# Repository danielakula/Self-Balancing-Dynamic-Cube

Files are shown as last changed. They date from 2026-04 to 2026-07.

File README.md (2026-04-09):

# Self-Balancing-Dynamic-Cube
Cubli inspired project for 3rd year undergraduate dissertation. Objective is to achieve balance on three edges, corner, and jump from face to edge.

# Contents
ESP32_Tests is written code for each tests done on the firmware.

Edge Balance is the code that implements an inner LQR control loop and a PI outer loop to achieve edge balance on Motor1.

UI Balance is a test which adds wireless UI onto Edge Balance.

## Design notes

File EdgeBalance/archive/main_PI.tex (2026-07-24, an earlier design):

#include <Arduino.h>
#include <Config.h>
#include "Driver.h"
#include "VoltageMonitor.h"
#include "IMU.h"
#include "LQR.h"
#include <atomic>

// Thread-safe mailboxes between Core 0 and Core 1
std::atomic<float> shared_target_torque(0.0f);
std::atomic<float> shared_motor_velocity(0.0f);
std::atomic<float> shared_motor_iq(0.0f);

// Make sure your spinlock flags are volatile so the compiler doesn't optimize them away!
volatile std::atomic<bool> spiRequested(false);
volatile std::atomic<bool> spiSafeToUse(false);

SPIClass hwSpi(1); 
Driver motor1(Motor1Pins, MotorTuning); 
VoltageMonitor battery(VSENSE_PIN, VSENSE_DIVIDER_RATIO, VSENSE_TRIM);

float target = 0.0f;

float target_angle = 0.0f;
float wheel_velocity_integral = 0.0f;

// Outer Loop PI Gains (Start very small!)
float Kp_outer = 0.003f; 
float Ki_outer = 0.0005f;

// Instantiate globally with your specific SPI pins
IMU_Sensor imu(ISM_CS, &hwSpi);

LQR lqr;

Commander command = Commander(Serial);

void taskFOC(void * pvParameters) {
    vTaskDelay(pdMS_TO_TICKS(500));
    // 1. Assassinate the Watchdog on Core 1 so we never have to yield!
    disableCore1WDT(); 

    // 2. Set this specific task to the highest possible FreeRTOS priority
    vTaskPrioritySet(NULL, configMAX_PRIORITIES - 1);

    for(;;) {
        // 1. The Spinlock Handshake
        if (spiRequested.load()) {
            // Core 0 needs the bus. Grant access.
            spiSafeToUse.store(true); 
            
            // Spin in place and wait for Core 0 to finish reading SPI sensors
            while (spiRequested.load()) { 
                // Do nothing. Just wait.
            }
            
            // Core 0 is done. Revoke access and resume math.
            spiSafeToUse.store(false); 
        } else {
            //motor1.setTarget(0.0f);
            motor1.setTarget(shared_target_torque.load());
            motor1.runFOC(); 
            shared_motor_velocity.store(motor1.getVelocity());
            shared_motor_iq.store(motor1.getCurrentQ());
        }
    }
}

void onKpOuter(char* cmd) { 
    command.scalar(&Kp_outer, cmd); 
    Serial.printf("Kp_outer set to: %.6f\n", Kp_outer);
}

void onKiOuter(char* cmd) { 
    command.scalar(&Ki_outer, cmd); 
    Serial.printf("Ki_outer set to: %.6f\n", Ki_outer);
}

void taskLQR(void *pvParameters) {
    uint32_t currentFaults = FAULT_NONE;
    static uint32_t lastFaults = 0xFFFFFFFF; 
    static uint32_t lastPrintTime = 0;
    const uint32_t PRINT_INTERVAL_MS = 200; 

    TickType_t xLastWakeTime = xTaskGetTickCount();
    const TickType_t xFrequency = pdMS_TO_TICKS(5); // 200 Hz LQR loop

    for(;;) {
        currentFaults = FAULT_NONE; 

        if (battery.isUnderVoltage(BATTERY_SAFE_MIN)) currentFaults |= FAULT_UNDER_VOLTAGE;
        if (battery.isOverVoltage(BATTERY_SAFE_MAX))  currentFaults |= FAULT_OVER_VOLTAGE;

        command.run();

        // =======================================================
        // BULLETPROOF SPI BUS ACCESS
        // =======================================================
        spiRequested.store(true); // 1. Ask Core 1 for the bus
        
        while (!spiSafeToUse.load()) { 
            // 2. Wait right here until Core 1 finishes its math and grants access
            delayMicroseconds(1); 
        }

        // 3. We now have 100% exclusive, safe access to the SPI hardware!
        if (motor1.hasHardwareFault()) currentFaults |= FAULT_DRV1;

        // State Machine (emergencyStop/enable might send SPI commands to the DRV chip)
        if (currentFaults != lastFaults) {
            if (currentFaults != FAULT_NONE) {
                motor1.emergencyStop();
                Serial.printf("\n[SYSTEM HALTED] Mask: 0x%08X\n", currentFaults);
            } else {
                motor1.enable();
            }
            lastFaults = currentFaults;
        }

        imu.update(); // Automatically calculates dt and updates state!

        spiRequested.store(false);
        
        float current_wheel_vel = shared_motor_velocity.load();
        
        // ==========================================
        // OUTER LOOP: Shift target angle based on wheel speed
        // ==========================================
        if (currentFaults == FAULT_NONE && abs(imu.getPitch()) < 0.35f) {
            
            // 1. Integrate the wheel velocity
            wheel_velocity_integral += current_wheel_vel * 0.005f; // dt = 5ms
            
            // Optional: Anti-windup for the integral so it doesn't lean too far
            if(wheel_velocity_integral > 500.0f) wheel_velocity_integral = 500.0f;
            if(wheel_velocity_integral < -500.0f) wheel_velocity_integral = -500.0f;

            // 2. Calculate the new target angle
            // If wheel spins positive, tilt positive to catch it.
            target_angle = (Kp_outer * current_wheel_vel) + (Ki_outer * wheel_velocity_integral);
            
            // Clamp target angle to a safe mechanical limit (e.g., +/- 3 degrees)
            const float MAX_TILT = 0.052f; // ~3 degrees in radians
            if (target_angle > MAX_TILT) target_angle = MAX_TILT;
            if (target_angle < -MAX_TILT) target_angle = -MAX_TILT;

        } else {
            // Robot fell over. Reset integrals.
            target_angle = 0.0f;
            wheel_velocity_integral = 0.0f;
        }

        // ==========================================
        // INNER LOOP: Standard LQR
        // ==========================================
        if (currentFaults == FAULT_NONE) {
            if (abs(imu.getPitch()) > 0.35f) {
                target = 0.0f; 
            } else {
                // Compute LQR, but calculate Theta ERROR relative to our new target!
                float theta_error = imu.getPitch() - target_angle;
                
                    target = -lqr.compute(
                    theta_error,            // x1: Angle ERROR
                    imu.getPitchRate(),     // x2: Cube Velocity
                    current_wheel_vel,      // x3: Wheel Velocity
                    0.005f                  // dt: 5ms
                );
            }
        }
        // if (currentFaults == FAULT_NONE) {
        //     if (std::abs(imu.getPitch()) > 0.35f) {
        //         target = 0.0f; 
        //         lqr.resetIntegral(); // Add a quick function to zero wheel_integral in LQR.cpp!
        //     } else {
        //             target = -lqr.compute(
        //             imu.getPitch(),         // x1: Raw Angle
        //             imu.getPitchRate(),     // x2: Cube Velocity
        //             current_wheel_vel,      // x3: Wheel Velocity
        //             0.005f                  // dt: 5ms
        //         );
        //     }
        // }

        // 5. Safely send the torque command to Core 0
        shared_target_torque.store(target);

        // 3. Telemetry Monitor
        if (millis() - lastPrintTime >= PRINT_INTERVAL_MS) {
            lastPrintTime = millis();
            
            // Plotter format: "Label1:Value1,Label2:Value2"
            Serial.printf("Angle:%.2f, PitchRate:%.2f, Target:%.2f, WheelVel:%.2f, Iq:%.2f, Battery:%.2fV\n", 
                          imu.getPitch()*RAD_TO_DEG, 
                          imu.getPitchRate(), target, current_wheel_vel, shared_motor_iq.load(), battery.readVoltage());
        }
        // if (millis() - lastPrintTime >= PRINT_INTERVAL_MS) {
        //     lastPrintTime = millis();
        //     float safe_iq = shared_motor_iq.load();
        //     Serial.printf("Batt: %05.2fV | Angle: %05.2f deg | Cube Velocity: %05.2f | Wheel Velocity:%05.1f Iq:%05.2f Target:%05.2f\n",
        //                   battery.readVoltage(), imu.getPitch(), imu.getPitchRate(), motor1.getVelocity(), motor1.getCurrentQ(), target);
        // }
        
        // Sleep until exactly 5ms have passed
        vTaskDelayUntil(&xLastWakeTime, xFrequency);
    }
}

void setup() {
    Serial.begin(115200);
    delay(2000); // Wait for Serial to initialize
    Serial.println("\n\n=======================================");
    Serial.println("       BALANCE BOT BOOTING...          ");  
    Serial.println("=======================================\n");

    SimpleFOCDebug::enable(&Serial);

    hwSpi.begin(MASTER_SCK, MASTER_MISO, MASTER_MOSI, -1);
    
    motor1.begin(&hwSpi);
    battery.begin();

    lqr.setCurrentLimit(MotorTuning.current_limit);
    
    if (!imu.init()) {
        Serial.println("IMU init failed!");
        while (1);
    }
    
    imu.calibrate();

    command.add('P', onKpOuter, "Outer Loop Kp");
    command.add('I', onKiOuter, "Outer Loop Ki");

    disableCore0WDT();

    // Pin FOC to Core 0 (Priority 5 - Highest)
    xTaskCreatePinnedToCore(taskFOC, "MotorTask", 8192, NULL, 5, NULL, 1);
    
    // Pin LQR to Core 1 (Priority 4 - High)
    xTaskCreatePinnedToCore(taskLQR, "LQR_Task", 8192, NULL, 4, NULL, 0);
}

void loop() {
    vTaskDelete(NULL); 
}

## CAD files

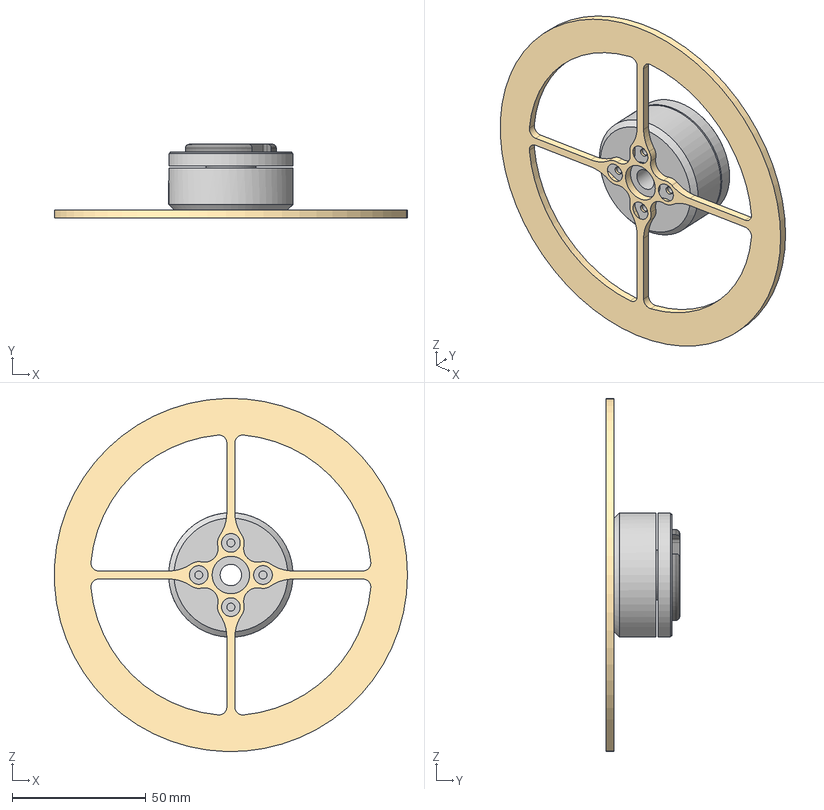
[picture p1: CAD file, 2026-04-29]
SIMULATIONS/Edge Balance/Discretised/Motor and Wheel (Assembly).step
131.9 x 27.5 x 132.0 mm
Motor and Wheel
15RW4S
GL40

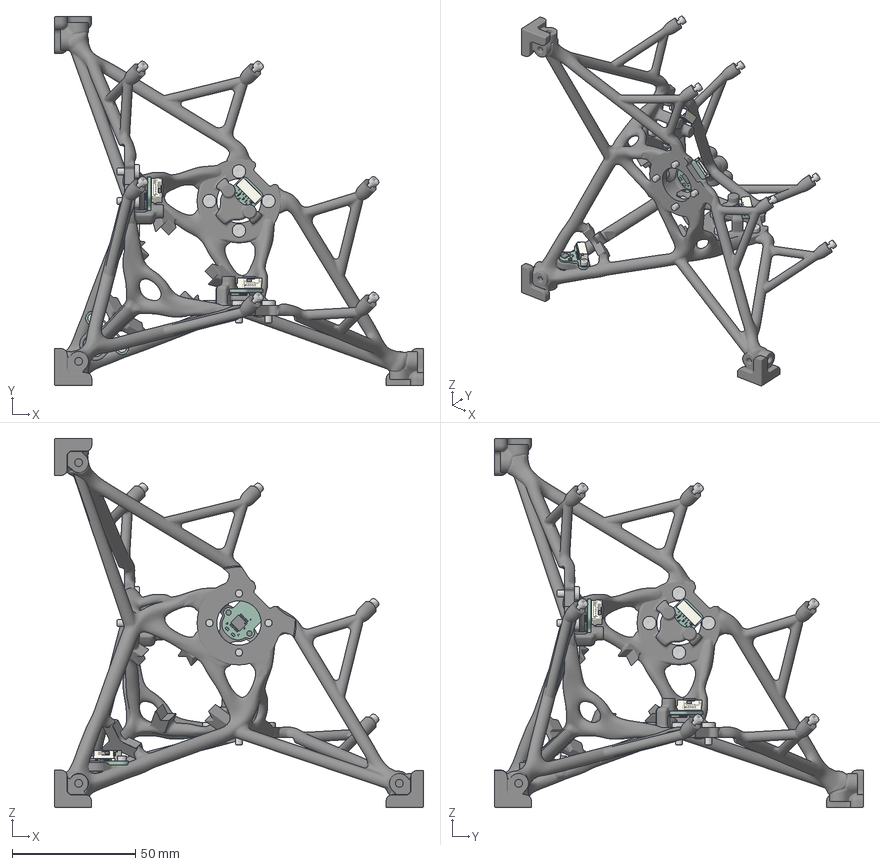
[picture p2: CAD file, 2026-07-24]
SIMULATIONS/Edge Balance/Discretised/coreModel.3mf
150.0 x 150.0 x 150.0 mm

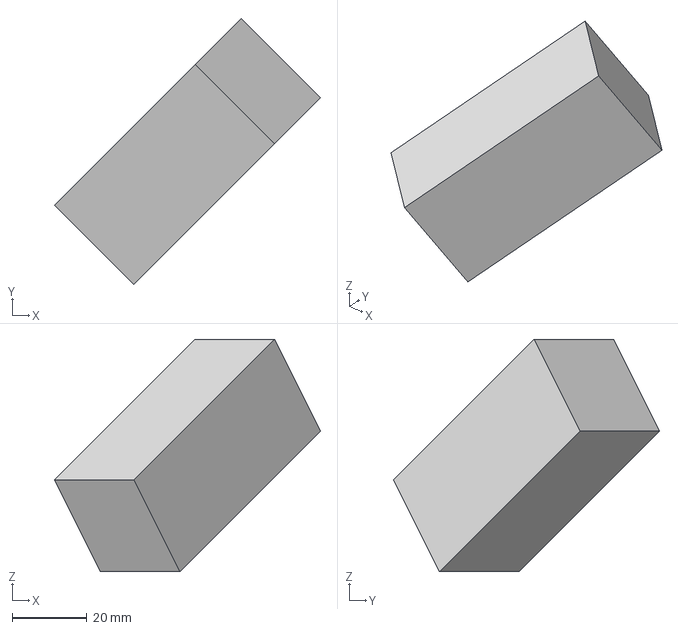
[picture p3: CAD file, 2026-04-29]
SIMULATIONS/Edge Balance/Discretised/BatteryModel.step
71.0 x 71.0 x 62.0 mm

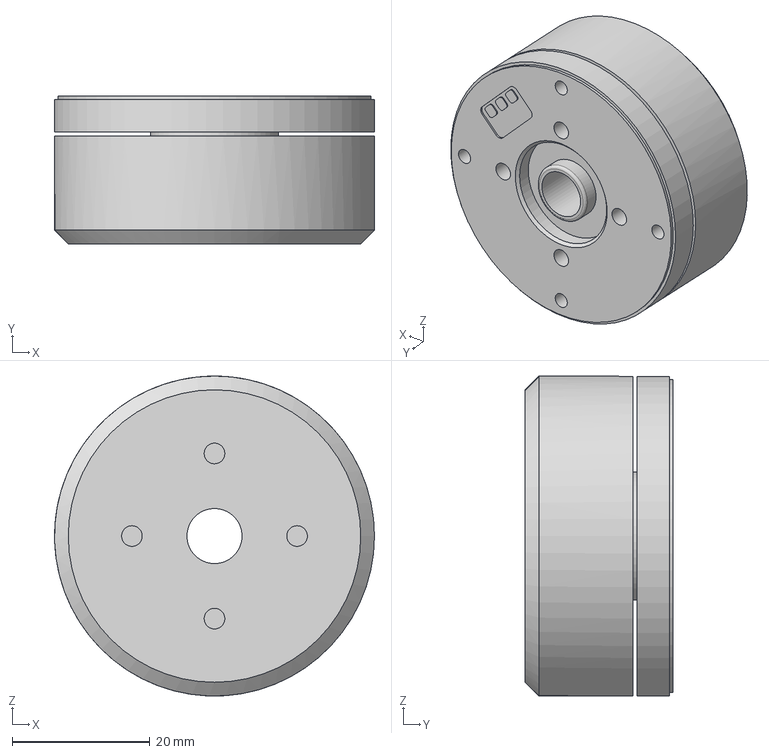
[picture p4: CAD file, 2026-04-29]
SIMULATIONS/Edge Balance/Discretised/Motor.step
46.5 x 21.5 x 46.5 mm

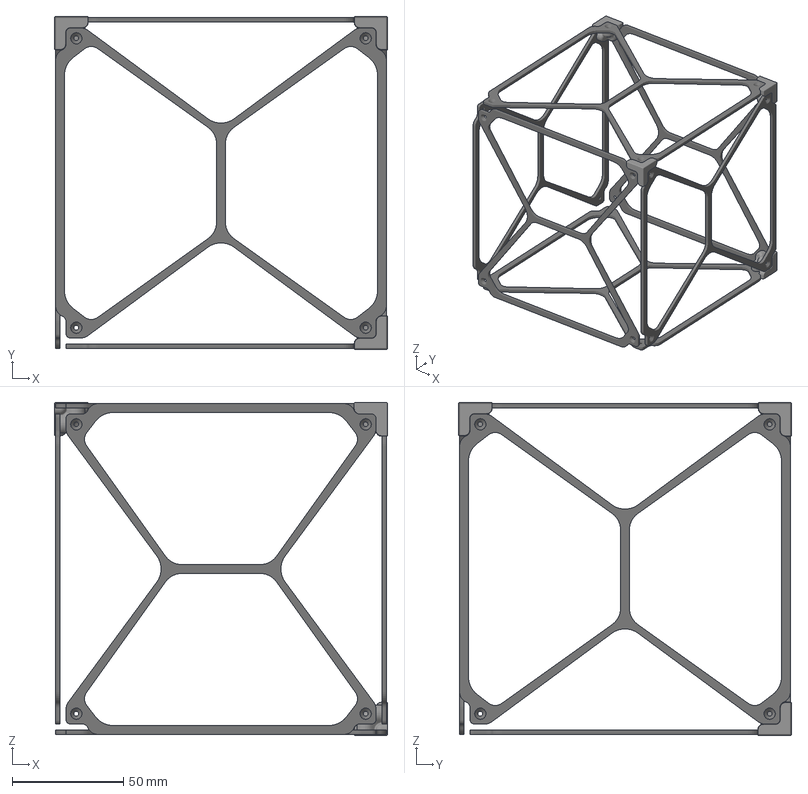
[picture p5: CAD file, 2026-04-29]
SIMULATIONS/Edge Balance/Discretised/FrameModel.3mf
150.0 x 150.0 x 150.0 mm

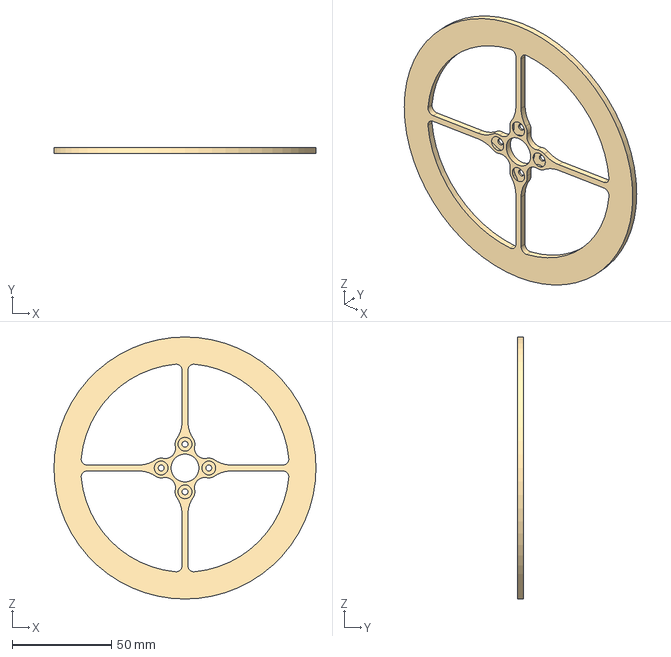
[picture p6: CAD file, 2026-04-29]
SIMULATIONS/Edge Balance/Discretised/RW.step
132.0 x 3.00 x 132.0 mm

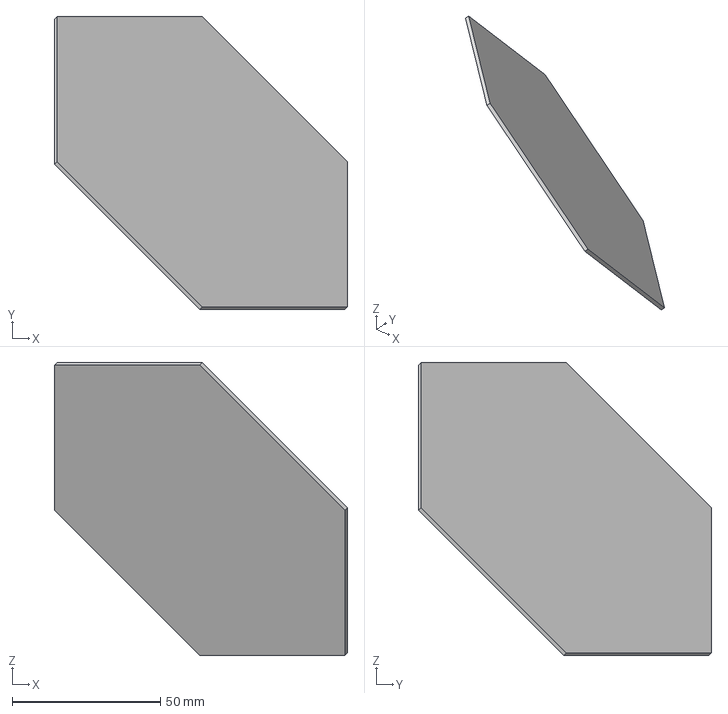
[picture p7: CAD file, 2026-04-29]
SIMULATIONS/Edge Balance/Discretised/PCBModel.step
98.9 x 98.9 x 98.9 mm

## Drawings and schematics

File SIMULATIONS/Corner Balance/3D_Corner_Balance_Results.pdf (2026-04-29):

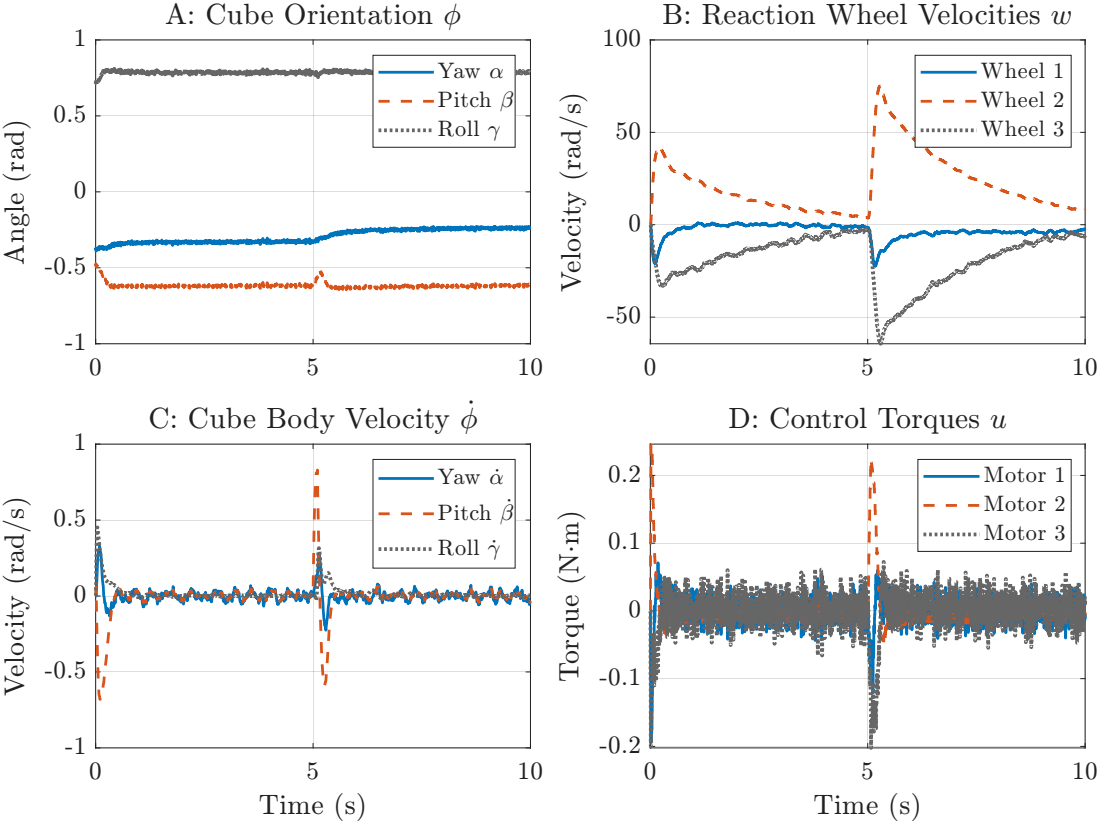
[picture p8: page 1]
gle (r; A: Cube Orientation ?; Yaw , Pitch - Roll .; Velo; cit; Wheel 1 Wheel 2 Wheel 3; Time (s); Yaw ,_ Pitch -_; Roll ._; D: Control Torques u; Motor 1 Motor 2 Motor 3

B: Reaction Wheel Velocities w

C: Cube Body Velocity ?_

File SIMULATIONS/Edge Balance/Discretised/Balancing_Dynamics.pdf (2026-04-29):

C
u

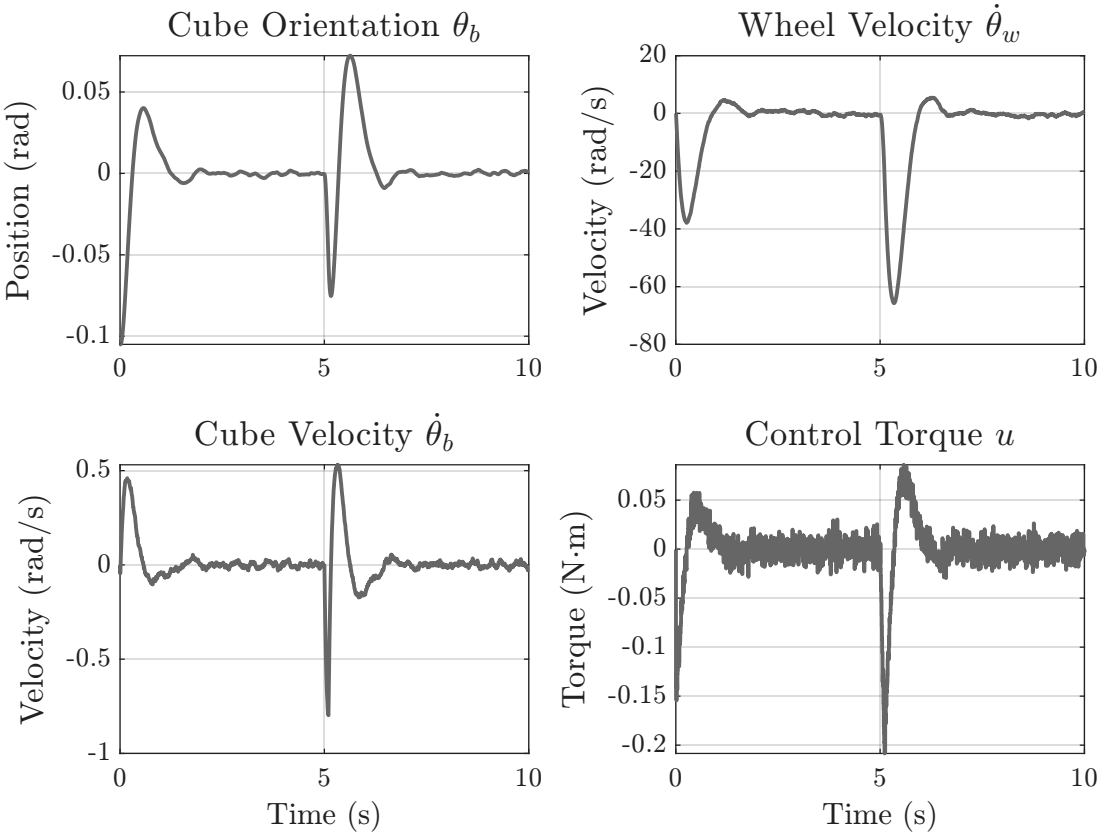
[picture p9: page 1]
Position (rad); Velocity (rad/s); Torque (N"m)

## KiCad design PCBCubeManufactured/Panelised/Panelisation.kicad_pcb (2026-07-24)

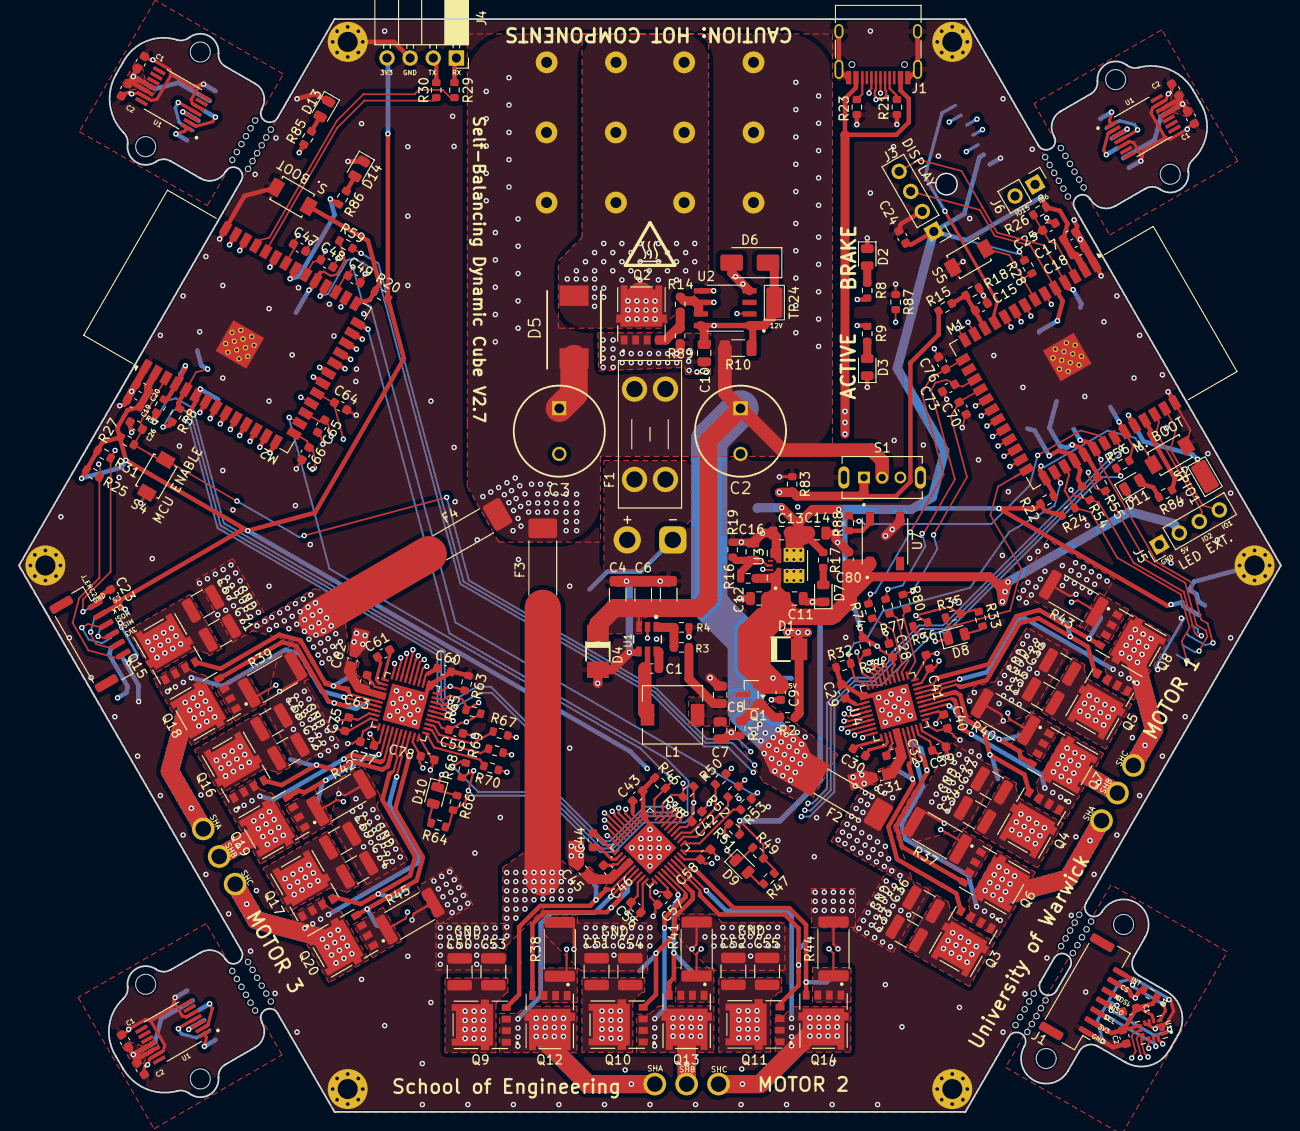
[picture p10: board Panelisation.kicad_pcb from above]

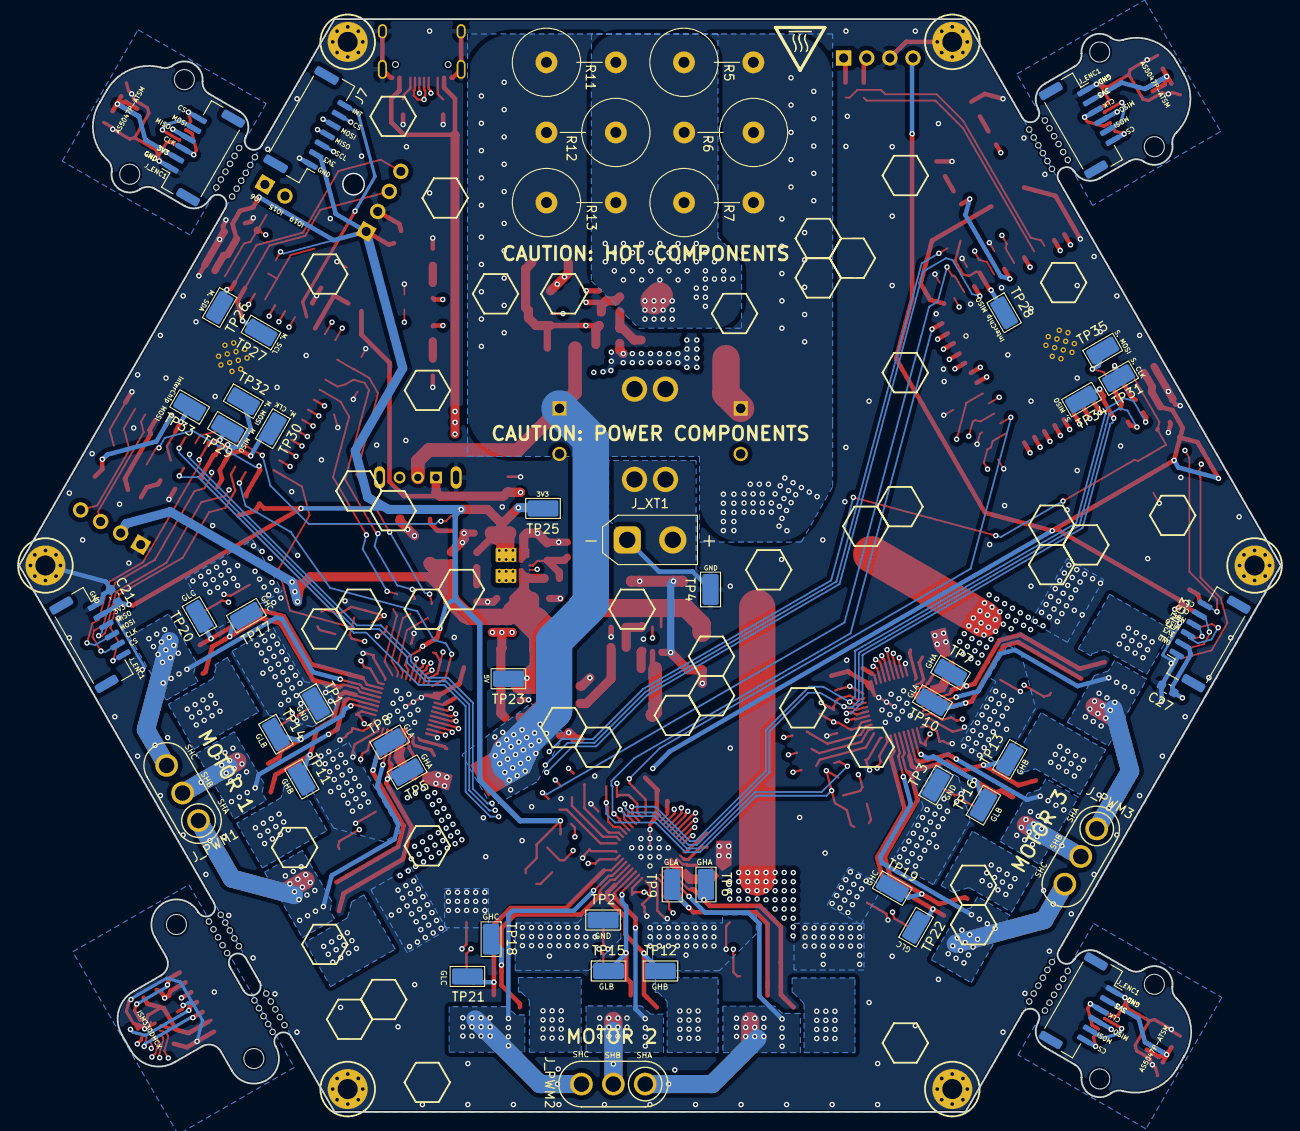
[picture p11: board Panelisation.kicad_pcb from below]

Board: 4 copper layers, 138.6 x 120.0 mm, 291 parts (53 on the bottom side), 181 nets.

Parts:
C1, C1#2, C1#3, C1#4, C1#5, C2#2, C15, C18, C20, C21, C23, C24, C27, C28, C31, C42, C45, C59, C62, C80: 100nF; C_0603_1608Metric
C2, C3: EEU-FC1H471L; CAPPRD500W85D1000H3200
C2#3, C2#4, C2#5, C9, C17, C19: 10uF; C_0603_1608Metric
C4, C5: 4.7uF; C_1206_3216Metric
C6: 100nF; C_1206_3216Metric
C7, C8: 47uF; C_0805_2012Metric
C10, C11, C16: 10uF; C_0805_2012Metric
C12: 100nF; C_0805_2012Metric
C13, C14: 22uF; C_0805_2012Metric
C25, C26, C29, C32, C43, C46, C60, C63: 1uF; C_0603_1608Metric
C30, C44, C61: 47nF; C_0603_1608Metric
C33, C34, C35, C36, C37, C38, C50, C51, C52, C53, C54, C55, C67, C68, C69, C71, C72, C74: 10uF; C_1210_3225Metric
C39, C40, C41, C56, C57, C58, C75, C77, C78: 1000pF; C_0603_1608Metric
C47, C48, C49, C64, C65, C66, C70, C73, C76: 2.2nF; C_0603_1608Metric
D1, D4: D_Schottky SS34; DO-214AC
D2, D8, D9, D10, D11, D14: LED R; LED_0805_2012Metric
D3, D7, D13: LED G; LED_0805_2012Metric
D5: D_Schottky SS1045; DIOM8059X256N
D6: 12V Zener; D_SMA
F1: 3568; Fuseholder_Blade_Mini_Keystone_3568
F2, F3, F4: 0456020.ER; FUSC10030X305N
H1, H2, H3, H4, H5, H6: MountingHole_Pad; MountingHole_2.19mm_M2_Pad_Via
J1, J7: Conn_01x07; JST_GH_BM07B-GHS-TBT_1x07-1MP_P1.25mm_Vertical
J1#2: USB_C_Receptacle_USB2.0_16P; USB_C_Receptacle_HRO_TYPE-C-31-M-12
J3, J5: Conn_01x04; PinHeader_1x04_P2.54mm_Vertical
J4: Conn_01x04; PinSocket_1x04_P2.54mm_Horizontal
J6: Conn_01x02; PinHeader_1x02_P2.54mm_Vertical
J_ENC1, J_ENC1#2, J_ENC1#3, J_ENC1#4, J_ENC2, J_ENC3: Conn_01x06; JST_GH_SM06B-GHS-TB_1x06-1MP_P1.25mm_Horizontal
J_PWM1, J_PWM2, J_PWM3: Conn_01x03; Amass_MR30PB-M
J_XT1: XT30UPB-M; AMASS_XT30UPB-M_1x02_P5.0mm_Vertical
L1: 4.7uH; L_6.3x6.3_H3
LOGO3, LOGO3#2: CAUTION HOT SURFACE; IEC_HotSurface_Small
M1, M2: ESP32-S3-WROOM-1
NT1, NT2, NT3, NT4, NT5, NT6, NT7, NT8, NT9, NT10: NetTie_2; NET-TIE-0.25mm
Q1: AO3401A; SOT-23
Q2, Q3, Q4, Q5, Q6, Q7, Q8, Q9, Q10, Q11, Q12, Q13, Q14, Q15, Q16, Q17, Q18, Q19, Q20: NTMFS5C612N; NTMFS5C430NT1G
R1, R1#2, R18, R19, R20, R22, R26, R27, R28, R87, R89: 10k; R_0603_1608Metric
R2: 1k; R_0603_1608Metric
R3, R15, R83: 100k; R_0603_1608Metric
R4: 19.1k; R_0603_1608Metric
R5, R6, R7, R11, R12, R13: AC07000003308JAC00; AC05
R8, R9: 2.2k; R_0603_1608Metric
R10: 330; R_1206_3216Metric
R14: 10; R_0603_1608Metric
R16: 15.8k; R_0603_1608Metric
R17: 470; R_0603_1608Metric
R21, R23: 5.1k; R_0603_1608Metric
R24, R25, R31, R32, R34, R35, R36, R46, R48, R49, R51, R63, R65, R66, R68: 10K; R_0603_1608Metric
R29, R30, R84, R85, R86, R88: 330; R_0603_1608Metric
R33, R47, R64: 1.5k; R_0603_1608Metric
R37, R38, R39, R40, R41, R42, R43, R44, R45: Shunt; R_2512_6332Metric
R50, R52, R53, R67, R69, R70, R74, R77, R80: 56; R_0603_1608Metric
R54, R55, R56, R57, R58, R59: 33; R_0603_1608Metric
S1: SS12D07VG4; SW_SS12D07VG4
S2, S3, S4, S5: TS-1088-AR02016; SW_TS-1088-AR02016
TP1, TP2, TP3, TP4, TP5, TP6, TP7, TP8, TP9, TP10, TP11, TP12, TP13, TP14, TP15, TP16, TP17, TP18, TP19, TP20, TP21, TP22, TP23, TP24, TP25, TP26, TP27, TP28, TP29, TP30, TP31, TP32, TP33, TP34, TP35: TestPoint; TestPoint_Keystone_5015_Micro_Mini
TPIO1: TestPoint; TestPoint_Keystone_5015_Micro_Mini
U1, U1#3, U1#5: AS5047P-ATSM; SOP65P640X120-14N
U1#2: LMR51625YFDDCR; DDC0006A-MFG
U1#4: ISM330DHCX; PQFN50P250X300X86-14N
U2: MCP1407-E_SN
U3: TPSM863253RDXR; VREG_TPSM863253RDXR
U4, U5, U6: DRV8323SRTAT; DRV8323SRTAT_update_solder
U7: WS2812B-B; LED_WS2812B-B

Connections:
+3V3: C1.1, C1#2.1, C1#4.1, C1#5.1, C2#2.1, C2#3.1, C2#4.1, C2#5.1, C13.2, C14.2, C17.2, C18.2, C19.2, C20.2, C21.2, C23.2, C24.2, C27.2, C28.2, C42.2, C59.2, J1.2, J3.1, J4.4, J7.2, J_ENC1.2, J_ENC1#2.2, J_ENC1#3.2, J_ENC1#4.2, J_ENC2.2, J_ENC3.2, M1.2 (3V3), M2.2 (3V3), R1#2.2, R17.2, R20.1, R22.1, R24.2, R25.2, R26.1, R27.1, R28.1, R31.2, R33.1, R34.2, R35.2, R36.2, R47.1, R48.2, R49.2, R51.2, R64.1, R65.2, R66.2, R68.2, TP25.1, U1.11 (VDD), U1.12 (VDD3V3), U1#3.11 (VDD), U1#3.12 (VDD3V3), U1#4.5 (VDD_IO), U1#4.8 (VDD), U1#5.11 (VDD), U1#5.12 (VDD3V3), U3.3 (VOUT), U3.7 (FB), U4.24 (VREF), U5.24 (VREF), U6.24 (VREF)
+5V: C9.2, C11.2, C12.2, C80.2, D1.1 (K), J5.2, Q1.2 (S), R16.1, TP23.1, U3.1 (VIN), U7.1 (VDD)
+5V Buck: C7.2, C8.2, L1.2, Q1.3 (D), R3.1
+5V USB: D1.2 (A), J1#2.A4 (VBUS), J1#2.A9 (VBUS), J1#2.B4 (VBUS), J1#2.B9 (VBUS), R2.1
/AO3401A Gate: Q1.1 (G), R1.1, R2.2
/BR3_EN: C16.2, R16.2, R19.2, U3.6 (EN)
/BR5_CB: C1#3.2, U1#2.6 (CB)
/BR5_FB: R3.2, R4.2, U1#2.1 (FB)
/BR5_SW: C1#3.1, L1.1, U1#2.5 (SW)
/BR_LEDG: D3.2 (A), R9.1
/BR_LEDR: D2.2 (A), R8.1
/CC1: J1#2.A5 (CC1), R21.2
/CC2: J1#2.B5 (CC2), R23.1
/CLK: J_ENC1.3, J_ENC1#3.3, J_ENC1#4.3, U1.2 (CLK), U1#3.2 (CLK), U1#5.2 (CLK)
/CS: J_ENC1.6, J_ENC1#3.6, J_ENC1#4.6, U1.1 (CSN), U1#3.1 (CSN), U1#5.1 (CSN)
/DIN: R88.2, U7.4 (DIN)
/Drain_Brake: D5.2 (A), Q2.5 (D), R5.1, R6.2, R7.1, R11.2, R12.1, R13.2
/Driver1/CPH1: C30.1, U4.2 (CPH)
/Driver1/CPL1: C30.2, U4.1 (CPL)
/Driver1/DVDD: C29.2, U4.33 (DVDD)
/Driver1/GHA: Q3.4 (G), TP5.1, U4.6 (GHA)
/Driver1/GHB: Q4.4 (G), TP11.1, U4.15 (GHB)
/Driver1/GHC: Q5.4 (G), TP17.1, U4.16 (GHC)
/Driver1/GLA: Q6.4 (G), TP8.1, U4.8 (GLA)
/Driver1/GLB: Q7.4 (G), TP14.1, U4.13 (GLB)
/Driver1/GLC: Q8.4 (G), TP20.1, U4.18 (GLC)
/Driver1/LED R1: D8.2 (A), R33.2
/Driver1/PhaseA: J_PWM1.1, Q3.1 (S), Q6.5 (D), U4.7 (SHA)
/Driver1/PhaseB: J_PWM1.2, Q4.1 (S), Q7.5 (D), U4.14 (SHB)
/Driver1/PhaseC: J_PWM1.3, Q5.1 (S), Q8.5 (D), U4.17 (SHC)
/Driver1/SNA: C39.1, NT4.2, U4.10 (SNA)
/Driver1/SNB: C40.1, NT2.2, U4.11 (SNB)
/Driver1/SNC: C41.1, NT3.2, U4.20 (SNC)
/Driver1/SPA: C39.2, Q6.1 (S), R37.1, U4.9 (SPA)
/Driver1/SPB: C40.2, Q7.1 (S), R40.1, U4.12 (SPB)
/Driver1/SPC: C41.2, Q8.1 (S), R43.1, U4.19 (SPC)
/Driver1/VCP1: C32.2, U4.3 (VCP)
/Driver1/VFuse: C31.2, C32.1, C33.2, C34.2, C35.2, C36.2, C37.2, C38.2, F2.1, Q3.5 (D), Q4.5 (D), Q5.5 (D), U4.4 (VM), U4.5 (VDRAIN)
/Driver2/CPH1: C44.1, U5.2 (CPH)
/Driver2/CPL1: C44.2, U5.1 (CPL)
/Driver2/DVDD: C43.2, U5.33 (DVDD)
/Driver2/GHA: Q9.4 (G), TP6.1, U5.6 (GHA)
/Driver2/GHB: Q10.4 (G), TP12.1, U5.15 (GHB)
/Driver2/GHC: Q11.4 (G), TP18.1, U5.16 (GHC)
/Driver2/GLA: Q12.4 (G), TP9.1, U5.8 (GLA)
/Driver2/GLB: Q13.4 (G), TP15.1, U5.13 (GLB)
/Driver2/GLC: Q14.4 (G), TP21.1, U5.18 (GLC)
/Driver2/LED R1: D9.2 (A), R47.2
/Driver2/PhaseA: J_PWM2.1, Q9.1 (S), Q12.5 (D), U5.7 (SHA)
/Driver2/PhaseB: J_PWM2.2, Q10.1 (S), Q13.5 (D), U5.14 (SHB)
/Driver2/PhaseC: J_PWM2.3, Q11.1 (S), Q14.5 (D), U5.17 (SHC)
/Driver2/SNA: C56.1, NT7.2, U5.10 (SNA)
/Driver2/SNB: C57.1, NT5.2, U5.11 (SNB)
/Driver2/SNC: C58.1, NT6.2, U5.20 (SNC)
/Driver2/SPA: C56.2, Q12.1 (S), R38.1, U5.9 (SPA)
/Driver2/SPB: C57.2, Q13.1 (S), R41.1, U5.12 (SPB)
/Driver2/SPC: C58.2, Q14.1 (S), R44.1, U5.19 (SPC)
/Driver2/VCP1: C46.2, U5.3 (VCP)
/Driver2/VFuse: C45.2, C46.1, C50.2, C51.2, C52.2, C53.2, C54.2, C55.2, F3.1, Q9.5 (D), Q10.5 (D), Q11.5 (D), U5.4 (VM), U5.5 (VDRAIN)
/Driver3/CPH1: C61.1, U6.2 (CPH)
/Driver3/CPL1: C61.2, U6.1 (CPL)
/Driver3/DVDD: C60.2, U6.33 (DVDD)
/Driver3/GHA: Q15.4 (G), TP7.1, U6.6 (GHA)
/Driver3/GHB: Q16.4 (G), TP13.1, U6.15 (GHB)
/Driver3/GHC: Q17.4 (G), TP19.1, U6.16 (GHC)
/Driver3/GLA: Q18.4 (G), TP10.1, U6.8 (GLA)
/Driver3/GLB: Q19.4 (G), TP16.1, U6.13 (GLB)
/Driver3/GLC: Q20.4 (G), TP22.1, U6.18 (GLC)
/Driver3/LED R1: D10.2 (A), R64.2
/Driver3/PhaseA: J_PWM3.1, Q15.1 (S), Q18.5 (D), U6.7 (SHA)
/Driver3/PhaseB: J_PWM3.2, Q16.1 (S), Q19.5 (D), U6.14 (SHB)
/Driver3/PhaseC: J_PWM3.3, Q17.1 (S), Q20.5 (D), U6.17 (SHC)
/Driver3/SNA: C75.1, NT10.2, U6.10 (SNA)
/Driver3/SNB: C77.1, NT8.2, U6.11 (SNB)
/Driver3/SNC: C78.1, NT9.2, U6.20 (SNC)
/Driver3/SPA: C75.2, Q18.1 (S), R39.1, U6.9 (SPA)
/Driver3/SPB: C77.2, Q19.1 (S), R42.1, U6.12 (SPB)
/Driver3/SPC: C78.2, Q20.1 (S), R45.1, U6.19 (SPC)
/Driver3/VCP1: C63.2, U6.3 (VCP)
/Driver3/VFuse: C62.2, C63.1, C67.2, C68.2, C69.2, C71.2, C72.2, C74.2, F4.1, Q15.5 (D), Q16.5 (D), Q17.5 (D), U6.4 (VM), U6.5 (VDRAIN)
/Gate_Brake: Q2.4 (G), R14.1, R89.1
/I.C. MISO: M2.31 (IO38), R59.1, TP28.1
/I.C. MOSI: M1.35 (IO42), R56.1, TP33.1
/LEDG: D7.2 (A), R17.1
/M. CLK: M1.30 (IO37), R54.1, TP30.1
/M. LEDR: D11.2 (A), R84.2
/M. MOSI: M1.31 (IO38), R55.1, TP32.1
/MISO: J_ENC1.4, J_ENC1#3.4, J_ENC1#4.4, U1.3 (MISO), U1#3.3 (MISO), U1#5.3 (MISO)
/MOSI: J_ENC1.5, J_ENC1#3.5, J_ENC1#4.5, U1.4 (MOSI), U1#3.4 (MOSI), U1#5.4 (MOSI)
/Out: R8.2, R14.2, U2.6 (OUT), U2.7 (OUT)
/S. CLK: M2.4 (IO4), R57.2, TP31.1
/S. LEDG: D13.2 (A), R85.2
/S. LEDR: D14.2 (A), R86.2
/S. MOSI: M2.5 (IO5), R58.2, TP35.1
/SRX: J4.1, R30.1
/STX: J4.2, R29.1
/V_XT30: F1.1, J_XT1.2 (+)
Debug1: J6.1, M1.6 (IO6)
Debug2: J6.2, M1.8 (IO15)
Display Button: M1.7 (IO7), R28.2, S5.2
Enable1: M1.28 (IO35), R32.2, U4.30 (ENABLE)
Enable2: M2.16 (IO46), R46.2, U5.30 (ENABLE)
Enable3: M2.14 (USB_D+), R63.2, U6.30 (ENABLE)
Fault1: D8.1 (K), M1.26 (IO45), R35.1, U4.25 (NFAULT)
Fault2: D9.1 (K), M2.26 (IO45), R49.1, U5.25 (NFAULT)
Fault3: D10.1 (K), M2.13 (USB_D-), R66.1, U6.25 (NFAULT)
GND: C1.2, C1#2.2, C1#4.2, C1#5.2, C2.2 (-), C2#2.2, C2#3.2, C2#4.2, C2#5.2, C3.2 (-), C4.1, C5.1, C6.1, C7.1, C8.1, C9.1, C10.2, C11.1, C12.1, C13.1, C14.1, C15.1, C16.1, C17.1, C18.1, C19.1, C20.1, C21.1, C23.1, C24.1, C25.2, C26.2, C27.1, C28.1, C29.1, C31.1, C33.1, C34.1, C35.1, C36.1, C37.1, C38.1, C42.1, C43.1, C45.1, C47.1, C48.1, C49.1, C50.1, C51.1, C52.1, C53.1, C54.1, C55.1, C59.1, C60.1, C62.1, C64.1, C65.1, C66.1, C67.1, C68.1, C69.1, C70.1, C71.1, C72.1, C73.1, C74.1, C76.1, C80.1, D2.1 (K), D3.1 (K), D4.2 (A), D6.2 (A), D7.1 (K), D11.1 (K), D13.1 (K), D14.1 (K), H1.1, H2.1, H3.1, H4.1, H5.1, H6.1, J1.1, J1#2.A1 (GND), J1#2.A12 (GND), J1#2.B1 (GND), J1#2.B12 (GND), J1#2.S1 (SHIELD), J3.2, J4.3, J5.1, J7.1, J_ENC1.1, J_ENC1#2.1, J_ENC1#3.1, J_ENC1#4.1, J_ENC2.1, J_ENC3.1, J_XT1.1 (-), M1.1 (GND), M1.40 (GND), M1.41 (GND), M2.1 (GND), M2.40 (GND), M2.41 (GND), NT2.1, NT3.1, NT4.1, NT5.1, NT6.1, NT7.1, NT8.1, NT9.1, NT10.1, Q2.1 (S), R1.2, R4.1, R18.1, R19.1, R21.1, R23.2, R32.1, R37.2, R38.2, R39.2, R40.2, R41.2, R42.2, R43.2, R44.2, R45.2, R46.1, R63.1, R83.1, R87.1, R89.2, S1.S1 (SHIELD), S1.S2 (SHIELD), S2.1, S3.1, S4.1, S5.1, TP1.1, TP2.1, TP3.1, TP4.1, U1.5 (TEST), U1.13 (GND), U1#2.4 (GND), U1#3.5 (TEST), U1#3.13 (GND), U1#4.2 (SDX), U1#4.3 (SCX), U1#4.6 (GND), U1#4.7 (GND), U1#5.5 (TEST), U1#5.13 (GND), U2.4 (GND), U2.5 (GND), U3.4 (PGND), U4.31 (CAL), U4.32 (AGND), U4.40 (PGND), U4.41 (EXP), U5.31 (CAL), U5.32 (AGND), U5.40 (PGND), U5.41 (EXP), U6.31 (CAL), U6.32 (AGND), U6.40 (PGND), U6.41 (EXP), U7.3 (VSS)
IMU_CS: J1.6, J7.6, M1.9 (IO16), R1#2.1, U1#4.12 (CS)
IMU_INT: J1.7, J7.7, M1.11 (IO18), U1#4.4 (INT1)
INHA1: M1.24 (IO47), U4.34 (INHA)
INHA2: M2.25 (IO48), U5.34 (INHA)
INHA3: M2.12 (IO8), U6.34 (INHA)
INHB1: M1.22 (IO14), U4.36 (INHB)
INHB2: M2.23 (IO21), U5.36 (INHB)
INHB3: M2.10 (IO17), U6.36 (INHB)
INHC1: M1.20 (IO12), U4.38 (INHC)
INHC2: M2.21 (IO13), U5.38 (INHC)
INHC3: M2.8 (IO15), U6.38 (INHC)
INLA1: M1.23 (IO21), U4.35 (INLA)
INLA2: M2.24 (IO47), U5.35 (INLA)
INLA3: M2.11 (IO18), U6.35 (INLA)
INLB1: M1.21 (IO13), U4.37 (INLB)
INLB2: M2.22 (IO14), U5.37 (INLB)
INLB3: M2.9 (IO16), U6.37 (INLB)
INLC1: M1.19 (IO11), U4.39 (INLC)
INLC2: M2.20 (IO12), U5.39 (INLC)
INLC3: M2.7 (IO7), U6.39 (INLC)
InterChip MISO: M1.34 (IO41), R59.2
InterChip MOSI: M2.30 (IO37), R56.2
LED1: J5.3, M1.38 (IO2)
LED2: J5.4, M1.39 (IO1)
LED3: M1.33 (IO40), R88.1
Master Boot: M1.27 (IO0), R22.2, S2.2
Master CLK: J1.3, J7.3, J_ENC1#2.3, R54.2, U1#4.13 (SCL), U4.28 (SCLK)
Master DRV1 CS: M1.25 (IO48), R34.1, U4.29 (NSCS)
Master EN: C25.1, M1.3 (EN), NT1.1, R26.2, S4.2
Master ENC1 CS: J_ENC1#2.6, M1.29 (IO36), R24.1
Master LEDR: M1.37 (TXD0), R84.1
Master MISO: J1.4, J7.4, J_ENC1#2.4, M1.32 (IO39), R36.1, TP29.1, U1#4.1 (SDO/SA0), U4.26 (SDO)
Master MOSI: J1.5, J7.5, J_ENC1#2.5, R55.2, U1#4.14 (SDA), U4.27 (SDI)
Master SCL: J3.3, M1.5 (IO5), TP27.1
Master SDA: J3.4, M1.4 (IO4), TP26.1
unnamed: R74.2, U4.23 (SOA)
unnamed: R77.2, U4.22 (SOB)
unnamed: R80.2, U4.21 (SOC)
unnamed: R50.2, U5.23 (SOA)
unnamed: R52.2, U5.22 (SOB)
unnamed: R53.2, U5.21 (SOC)
unnamed: R67.2, U6.23 (SOA)
unnamed: R69.2, U6.22 (SOB)
unnamed: R70.2, U6.21 (SOC)
SOA1: C76.2, M1.15 (IO3), R74.1
SOA2: C47.2, M2.34 (IO41), R50.1
SOA3: C64.2, M2.19 (IO11), R67.1
SOB1: C73.2, M1.17 (IO9), R77.1
SOB2: C48.2, M2.32 (IO39), R52.1
SOB3: C65.2, M2.17 (IO9), R69.1
SOC1: C70.2, M1.18 (IO10), R80.1
SOC2: C49.2, M2.29 (IO36), R53.1
SOC3: C66.2, M2.15 (IO3), R70.1
Slave Boot: M2.27 (IO0), R20.2, S3.2
Slave CLK: J_ENC2.3, J_ENC3.3, R57.1, U5.28 (SCLK), U6.28 (SCLK)
Slave DRV2 CS: M2.28 (IO35), R48.1, U5.29 (NSCS)
Slave DRV3 CS: M2.18 (IO10), R65.1, U6.29 (NSCS)
Slave EN: C26.1, M2.3 (EN), NT1.2, R27.2
Slave ENC2 CS: J_ENC2.6, M2.39 (IO1), R25.1
Slave ENC3 CS: J_ENC3.6, M2.38 (IO2), R31.1
Slave LEDG: M2.35 (IO42), R85.1
Slave LEDR: M2.33 (IO40), R86.1
Slave MISO: J_ENC2.4, J_ENC3.4, M2.6 (IO6), R51.1, R68.1, TP34.1, U5.26 (SDO), U6.26 (SDO)
Slave MOSI: J_ENC2.5, J_ENC3.5, R58.1, U5.27 (SDI), U6.27 (SDI)
Slave RX: M2.36 (RXD0), R29.2
Slave TX: M2.37 (TXD0), R30.2
TestPoint M.: M1.36 (RXD0), TPIO1.1
USB_D+: J1#2.A6 (D+), J1#2.B6 (D+), M1.14 (USB_D+)
USB_D-: J1#2.A7 (D-), J1#2.B7 (D-), M1.13 (USB_D-)
VBAT: C2.1 (+), C3.1 (+), C4.2, C5.2, C6.2, D4.1 (K), D5.1 (K), F1.2, F2.2, F3.2, F4.2, R5.2, R6.1, R7.2, R10.2, R11.1, R12.2, R13.1, S1.2, U1#2.3 (VIN)
VBat Sense: C15.2, M1.12 (IO8), R15.1, R18.2
VDD: C10.1, D6.1 (K), R9.2, R10.1, TP24.1, U2.1 (VDD), U2.8 (VDD)
VSwitch: R15.2, R83.2, S1.1, U1#2.2 (EN)
Voltage Protection: M1.10 (IO17), R87.2, U2.2 (INPUT)

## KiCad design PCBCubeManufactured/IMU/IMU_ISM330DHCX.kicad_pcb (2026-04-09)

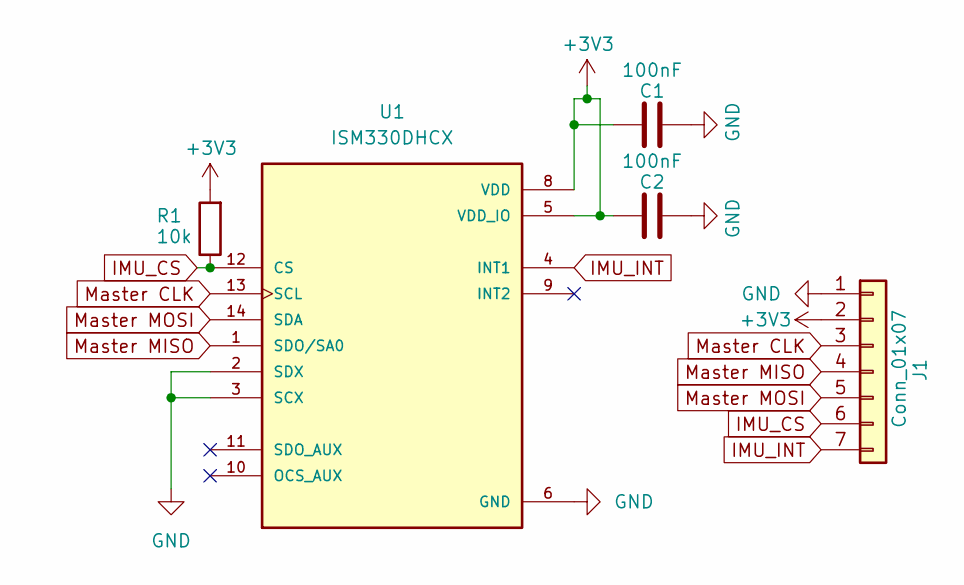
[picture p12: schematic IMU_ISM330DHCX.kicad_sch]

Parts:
C1, C2: 100nF; C_0603_1608Metric; LCSC C14663
J1: Conn_01x07; JST_GH_BM07B-GHS-TBT_1x07-1MP_P1.25mm_Vertical
R1: 10k; R_0603_1608Metric; LCSC C25804
U1: ISM330DHCX; PQFN50P250X300X86-14N; PARTREV 7; LCSC C2655101

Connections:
+3V3: C1.1, C2.1, J1.2, R1.2, U1.5 (VDD_IO), U1.8 (VDD)
GND: C1.2, C2.2, J1.1, U1.2 (SDX), U1.3 (SCX), U1.6 (GND), U1.7 (GND)
IMU_CS: J1.6, R1.1, U1.12 (CS)
IMU_INT: J1.7, U1.4 (INT1)
Master CLK: J1.3, U1.13 (SCL)
Master MISO: J1.4, U1.1 (SDO/SA0)
Master MOSI: J1.5, U1.14 (SDA)

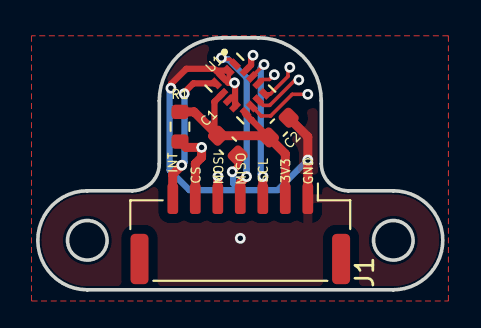
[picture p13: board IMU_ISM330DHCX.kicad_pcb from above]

Board: 4 copper layers, 22.5 x 14.0 mm, 5 parts (0 on the bottom side), 7 nets.

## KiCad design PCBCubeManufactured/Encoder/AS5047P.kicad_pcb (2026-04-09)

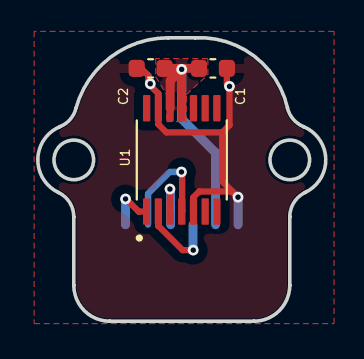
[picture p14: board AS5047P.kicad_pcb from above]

Board: 4 copper layers, 16.0 x 15.7 mm, 4 parts (1 on the bottom side), 6 nets.

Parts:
C1: 100nF; C_0603_1608Metric
C2: 10uF; C_0603_1608Metric
J_ENC1: Conn_01x06; JST_GH_SM06B-GHS-TB_1x06-1MP_P1.25mm_Horizontal
U1: AS5047P-ATSM; SOP65P640X120-14N

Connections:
+3V3: C1.1, C2.1, J_ENC1.2, U1.11 (VDD), U1.12 (VDD3V3)
/CLK: J_ENC1.3, U1.2 (CLK)
/CS: J_ENC1.6, U1.1 (CSN)
/MISO: J_ENC1.4, U1.3 (MISO)
/MOSI: J_ENC1.5, U1.4 (MOSI)
GND: C1.2, C2.2, J_ENC1.1, U1.5 (TEST), U1.13 (GND)

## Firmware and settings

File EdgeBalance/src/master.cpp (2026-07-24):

#include <Arduino.h>
#include <Config.h>
#include "Driver.h"
#include "VoltageMonitor.h"
#include "IMU.h"
#include "LQR.h"
#include "InterchipComms.h"
#include <atomic>

// Define a custom fault code for the web dashboard Disable button
#define FAULT_USER_DISABLE 0x80000000 

// --- Active Parameters ---
float lqr_k1 = DEFAULT_LQR_K1;
float lqr_k2 = DEFAULT_LQR_K2;
float lqr_k3 = DEFAULT_LQR_K3;

float Kp_outer = DEFAULT_KP_OUTER; 
float Ki_outer = DEFAULT_KI_OUTER;

// --- Initialisation ---
float target = 0.0f;
float target_angle = 0.0f;
float wheel_velocity_integral = 0.0f;

// --- Thread-safe mailboxes between Core 0 and Core 1 ---
std::atomic<float> shared_target_torque(0.0f);
std::atomic<float> shared_motor_velocity(0.0f);
std::atomic<float> shared_motor_iq(0.0f);

volatile std::atomic<bool> spiRequested(false);
volatile std::atomic<bool> spiSafeToUse(false);

// --- Global Objects ---
SPIClass hwSpi(1);
HardwareSerial uartLink(1); 
Driver motor1(Motor1Pins, MotorTuning); 
VoltageMonitor battery(VSENSE_PIN, VSENSE_DIVIDER_RATIO, VSENSE_TRIM);
InterchipComms comms(uartLink, MASTER_RX, MASTER_TX); 
IMU_Sensor imu(ISM_CS, &hwSpi);
LQR lqr;

// =======================================================
// CORE 1: MOTOR CONTROL TASK (Fast Loop)
// =======================================================
void taskFOC(void * pvParameters) {
    vTaskDelay(pdMS_TO_TICKS(500));
    disableCore1WDT(); 
    vTaskPrioritySet(NULL, configMAX_PRIORITIES - 1);

    for(;;) {
        if (spiRequested.load()) {
            spiSafeToUse.store(true); 
            while (spiRequested.load()) { /* Spin and wait */ }
            spiSafeToUse.store(false); 
        } else {
            motor1.setTarget(shared_target_torque.load());
            motor1.runFOC(); 
            shared_motor_velocity.store(motor1.getVelocity());
            shared_motor_iq.store(motor1.getCurrentQ());
        }
    }
}

// =======================================================
// CORE 0: LQR & TELEMETRY TASK (200Hz)
// =======================================================
void taskLQR(void *pvParameters) {
    uint32_t currentFaults = FAULT_NONE;
    static uint32_t lastFaults = 0xFFFFFFFF; 
    static uint32_t lastPrintTime = 0;

    TickType_t xLastWakeTime = xTaskGetTickCount();
    const TickType_t xFrequency = pdMS_TO_TICKS(TASK_LOOP_FREQUENCY); // 200 Hz
    const float dt = TASK_LOOP_FREQUENCY / 1000.0f; // Calculate dt strictly from config

    for(;;) {
        currentFaults = FAULT_NONE; 

        // --- 1. FAULT MONITORING ---
        if (battery.isUnderVoltage(BATTERY_SAFE_MIN)) currentFaults |= FAULT_UNDER_VOLTAGE;
        if (battery.isOverVoltage(BATTERY_SAFE_MAX))  currentFaults |= FAULT_OVER_VOLTAGE;
        
        comms.update(); 
        if (!comms.isConnectionAlive(100)) currentFaults |= FAULT_COMMS_LOST;
        if (comms.getRobotState() == 0) currentFaults |= FAULT_USER_DISABLE;

        // --- 2. APPLY INCOMING TUNING PARAMETERS ---
        // PI Tuning
        if (comms.getKpOuter() > 0.00001f) Kp_outer = comms.getKpOuter();
        if (comms.getKiOuter() > 0.00001f) Ki_outer = comms.getKiOuter();
        
        // LQR Tuning (Ignore exact 0.0f on boot)
        if (comms.getK1() != 0.0f) { 
            lqr_k1 = comms.getK1();
            lqr_k2 = comms.getK2();
            lqr_k3 = comms.getK3();
            lqr.setGains(lqr_k1, lqr_k2, lqr_k3);
        }

        // IMU Tuning
        if (comms.getBaseAlpha() > 0.0f) imu.setAlpha(comms.getBaseAlpha());
        if (comms.getAccelTol() > 0.0f) imu.setAccelTolerance(comms.getAccelTol());

        // --- 3. BULLETPROOF SPI BUS ACCESS ---
        spiRequested.store(true); 
        while (!spiSafeToUse.load()) { delayMicroseconds(1); }

        if (motor1.hasHardwareFault()) currentFaults |= FAULT_DRV1;
        currentFaults |= comms.getFaultCode(); 
        
        // State Machine execution during safe SPI window
        if (currentFaults != lastFaults) {
            if (currentFaults != FAULT_NONE) {
                motor1.emergencyStop();
                Serial.printf("\n[SYSTEM HALTED] Mask: 0x%08X\n", currentFaults);
            } else {
                motor1.enable();
            }
            lastFaults = currentFaults;
        }

        imu.update(); // Calculate internal kinematics
        spiRequested.store(false); // RELEASE SPI BUS!
        
        float current_wheel_vel = shared_motor_velocity.load();
        
        // --- 4. OUTER LOOP (PI) ---
        if (currentFaults == FAULT_NONE && abs(imu.getPitch()) < ANGLE_THRESHOLD) {
            wheel_velocity_integral += current_wheel_vel * dt; 
            
            if(wheel_velocity_integral > INTEGRAL_CLAMPING) wheel_velocity_integral = INTEGRAL_CLAMPING;
            if(wheel_velocity_integral < -INTEGRAL_CLAMPING) wheel_velocity_integral = -INTEGRAL_CLAMPING;

            // Calculate PI target, PLUS the manual target pitch from the Web Dashboard slider!
            target_angle = (Kp_outer * current_wheel_vel) + (Ki_outer * wheel_velocity_integral) + comms.getTargetPitch();
            
            if (target_angle > MAX_PITCH_TARGET) target_angle = MAX_PITCH_TARGET;
            if (target_angle < -MAX_PITCH_TARGET) target_angle = -MAX_PITCH_TARGET;

        } else {
            target_angle = 0.0f;
            wheel_velocity_integral = 0.0f;
        }

        // --- 5. INNER LOOP (LQR) ---
        if (currentFaults == FAULT_NONE) {
            if (abs(imu.getPitch()) > ANGLE_THRESHOLD) {
                target = 0.0f; 
            } else {
                float theta_error = imu.getPitch() - target_angle;
                
                target = -lqr.compute(
                    theta_error,            // x1: Angle ERROR
                    imu.getPitchRate(),     // x2: Cube Velocity
                    current_wheel_vel,      // x3: Wheel Velocity
                    dt                      // dt: Fixed time step
                );
            }
        } else {
            target = 0.0f;
        }

        shared_target_torque.store(target);

        // --- 6. SEND TELEMETRY TO WI-FI MCU ---
        comms.setTelemetryTuning(Kp_outer, Ki_outer, lqr_k1, lqr_k2, lqr_k3);
        comms.setTelemetryMotors(current_wheel_vel, 0, 0, shared_motor_iq.load(), 0, 0);
        comms.setTelemetryKinematics(imu.getPitch() * RAD_TO_DEG, imu.getPitchRate() * RAD_TO_DEG, currentFaults);
        
        // Include the Mahony raw data stream!
        comms.setTelemetryIMU(imu.getAccelX(), imu.getAccelY(), imu.getAccelZ(), 
                              imu.getGyroX(), imu.getGyroY(), imu.getGyroZ());
        
        comms.sendTelemetryPacket();

        // --- 7. DEBUG OUTPUT ---
        if (millis() - lastPrintTime >= PRINT_INTERVAL_MS) {
            lastPrintTime = millis();
            Serial.printf("Angle:%.2f, TargetAngle:%.2f, WheelVel:%.2f, Kp:%.4f, Faults:0x%X\n", 
                          imu.getPitch()*RAD_TO_DEG, target_angle*RAD_TO_DEG, current_wheel_vel, Kp_outer, currentFaults);
        }
        
        vTaskDelayUntil(&xLastWakeTime, xFrequency);
    }
}

void setup() {
    Serial.begin(115200);
    comms.begin(1000000); 

    delay(2000); 
    Serial.println("\n\n=======================================");
    Serial.println("       BALANCE BOT BOOTING...          ");  
    Serial.println("=======================================\n");

    SimpleFOCDebug::enable(&Serial);
    hwSpi.begin(MASTER_SCK, MASTER_MISO, MASTER_MOSI, -1);
    
    motor1.begin(&hwSpi);
    battery.begin();
    lqr.setCurrentLimit(MotorTuning.current_limit);
    
    if (!imu.init()) {
        Serial.println("IMU init failed!");
        while (1);
    }
    imu.calibrate();

    disableCore0WDT();

    xTaskCreatePinnedToCore(taskFOC, "MotorTask", 8192, NULL, 5, NULL, 1);
    xTaskCreatePinnedToCore(taskLQR, "LQR_Task", 8192, NULL, 4, NULL, 0);
}

void loop() {
    vTaskDelete(NULL); 
}

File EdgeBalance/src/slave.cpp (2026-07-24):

#include <Arduino.h>
#include <WiFi.h>
#include <AsyncTCP.h>
#include <ESPAsyncWebServer.h>
#include <ArduinoJson.h>
#include <LittleFS.h>
#include "InterchipComms.h"
#include "Config.h"

// --- Global Objects ---
AsyncWebServer server(80);
AsyncWebSocket ws("/ws");
InterchipComms comms(Serial1, SLAVE_RX, SLAVE_TX);

// --- WebSocket Message Handler ---
void handleWebSocketMessage(void *arg, uint8_t *data, size_t len) {
    AwsFrameInfo *info = (AwsFrameInfo*)arg;
    if (info->final && info->index == 0 && info->len == len && info->opcode == WS_TEXT) {
        
        StaticJsonDocument<256> doc;
        DeserializationError error = deserializeJson(doc, data, len);
        if (error) {
            Serial.print("JSON Parse Failed: ");
            Serial.println(error.c_str());
            return;
        }

        const char* cmd = doc["cmd"];
        bool updated = false;

        if (strcmp(cmd, "state") == 0) {
            comms.setRobotState(doc["state"], doc["edge"]);
            updated = true;
        } 
        else if (strcmp(cmd, "tune_pitch") == 0) {
            comms.setPitchTarget(doc["val"]);
            updated = true;
        } 
        else if (strcmp(cmd, "tune_pi") == 0) {
            comms.setPI(doc["kp"], doc["ki"]);
            updated = true;
        } 
        else if (strcmp(cmd, "tune_lqr") == 0) {
            comms.setLQRWeights(doc["k1"], doc["k2"], doc["k3"]);
            updated = true;
        }

        if (updated) {
            comms.sendCommandPacket();
            Serial.println("Updated Parameters Sent to Control MCU");
        }
    }
}

void onEvent(AsyncWebSocket *server, AsyncWebSocketClient *client, AwsEventType type, void *arg, uint8_t *data, size_t len) {
    if (type == WS_EVT_DATA) {
        handleWebSocketMessage(arg, data, len);
    } else if (type == WS_EVT_CONNECT) {
        Serial.println("Phone Connected!");
    } else if (type == WS_EVT_DISCONNECT) {
        Serial.println("Phone Disconnected!");
    }
}

// =======================================================
// CORE 0: COMMS & TELEMETRY TASK
// =======================================================
void taskWiFiTelemetry(void *pvParameters) {
    unsigned long lastTelemetryTime = 0;
    const unsigned long TELEMETRY_INTERVAL = 50; // 20Hz

    for(;;) {
        // 1. Keep parsing incoming packets from the Control MCU
        comms.update();

        // 2. Broadcast Telemetry to the Phone
        if (millis() - lastTelemetryTime > TELEMETRY_INTERVAL) {
            lastTelemetryTime = millis();

            if (ws.count() > 0) {
                StaticJsonDocument<512> doc; 

                // Kinematics & Faults
                doc["p"] = comms.getPitch();
                doc["pr"] = comms.getPitchRate();
                doc["f"] = comms.getFaultCode();

                // Active sync data
                doc["sync_kp"] = comms.getActiveKp();
                doc["sync_ki"] = comms.getActiveKi();
                doc["sync_k1"] = comms.getActiveK1();
                doc["sync_k2"] = comms.getActiveK2();
                doc["sync_k3"] = comms.getActiveK3();

                // Motor Telemetry
                JsonArray mv = doc.createNestedArray("mv");
                mv.add(comms.getMotorVel(1)); mv.add(comms.getMotorVel(2)); mv.add(comms.getMotorVel(3));
                
                JsonArray mc = doc.createNestedArray("mc");
                mc.add(comms.getMotorCur(1)); mc.add(comms.getMotorCur(2)); mc.add(comms.getMotorCur(3));

                // IMU Telemetry
                JsonArray a = doc.createNestedArray("a");
                a.add(comms.getIMU('x', 'a')); a.add(comms.getIMU('y', 'a')); a.add(comms.getIMU('z', 'a'));
                
                JsonArray g = doc.createNestedArray("g");
                g.add(comms.getIMU('x', 'g')); g.add(comms.getIMU('y', 'g')); g.add(comms.getIMU('z', 'g'));

                // Serialize and blast out via WebSockets
                char buffer[512];
                size_t len = serializeJson(doc, buffer);
                ws.textAll(buffer, len);
            }
        }
        
        // Yield to the FreeRTOS scheduler to prevent Watchdog panics on Core 0
        vTaskDelay(pdMS_TO_TICKS(1)); 
    }
}

void setup() {
    Serial.begin(115200);      
    comms.begin(1000000);      

    if (!LittleFS.begin(true)) {
        Serial.println("LittleFS Mount Failed");
        return;
    }

    WiFi.mode(WIFI_STA);
    WiFi.begin(WIFI_SSID, WIFI_PASS);
    Serial.print("Connecting to WiFi");
    while (WiFi.status() != WL_CONNECTED) {
        delay(500);
        Serial.print(".");
    }
    Serial.println();
    Serial.print("Dashboard IP: ");
    Serial.println(WiFi.localIP());

    server.on("/", HTTP_GET, [](AsyncWebServerRequest *request){
        request->send(LittleFS, "/index.html", "text/html");
    });

    ws.onEvent(onEvent);
    server.addHandler(&ws);
    server.begin();
    
    // --- PIN THE COMMS TASK TO CORE 0 ---
    // Priority 1 is fine for telemetry. 
    xTaskCreatePinnedToCore(taskWiFiTelemetry, "CommsTask", 8192, NULL, 1, NULL, 0);

    Serial.println("System Ready. Core 1 is now free.");
}

void loop() {
    // Delete the default Arduino loop task, freeing Core 1 completely!
    vTaskDelete(NULL); 
}

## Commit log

2026-04-09 Update README with project details and test descriptions
    Added descriptions for ESP32_Tests, Edge Balance, and Motor Control sections.
2026-07-24 adding comments to driver and config
